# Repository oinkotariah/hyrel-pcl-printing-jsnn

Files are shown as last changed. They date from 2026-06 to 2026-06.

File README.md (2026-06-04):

# hyrel-pcl-printing-jsnn

PrusaSlicer configs, G-code, and patch scripts for **3D printing PCL (polycaprolactone) on the Hyrel SYSTEM 30M** by Direct Ink Writing (DIW), at the IMPACT Lab, JSNN (the Joint School of Nanoscience and Nanoengineering — NC A&T + UNCG).

The point of this repo is to **make the lab's settings reproducible** — so when we publish, the methods section can point here and anyone can re-slice the same STL with the same configs and get the same G-code.

---

## Project status — June 4, 2026 (Day 3 pivot)

**The live project is now a flexible conductive PCL/graphite composite, not bone-tissue scaffolds.** Same printer, same PCL, but the application has shifted to **flexible electronics**:

- **Goal:** PCL loaded with graphite at 5 loadings (10–30 %), formed into dog-bone specimens, measure conductivity to locate the **percolation threshold**. Poster now, paper later.
- **Hardware:** Hyrel SYSTEM 30M currently **down** (heads/nozzles reordered). Fallback fabrication route = melt-and-mould-cast.
- **Papers in scope** (5): Yuk 2020 (north star · printing a conductor), Zhang 2021 (PCL DIW how-to), Teixeira 2026 (parameter optimization), Liu 2018 (PCL melt-extrusion crystallinity), Woodruff & Hutmacher 2010 (PCL review). All summarized in `docs/research_notes/`.

The travel-speed G-code fix story below remains accurate as historical / methodological context. The `gcode/` and `configs/` folders are still the canonical settings if the Hyrel comes back online.

**For full current context** (paste into a fresh chat to restore state): see `docs/PROJECT_HANDOFF.md`.

---

## Quick start

If you just want to print our calibration cube:

1. Open PrusaSlicer 2.9.2 or newer.
2. Load these three profiles (under Print Settings, Filament Settings, Printer Settings):
   - **Print:** `configs/prusaslicer/print/PCL_DIW_25print_60travel_FIXED.ini`
   - **Filament:** `configs/prusaslicer/filament/ABS-30M_240C_80Cbed.ini` *(placeholder — will be replaced with a PCL-specific profile, see [Known issues](#known-issues))*
   - **Printer:** `configs/prusaslicer/printer/30M-ESR_T1_Heated.ini`
3. Import `gcode/cube_10x10x10_2mm_Corners/source.stl`.
4. Slice. The output should be ~7,000 lines and use **two F-values**: F1500 (25 mm/s, print) and F3600 (60 mm/s, travel).
5. Load the resulting G-code into Repetrel.
6. Print.

If PrusaSlicer isn't available, the pre-sliced fixed G-code is at `gcode/cube_10x10x10_2mm_Corners/travel_fixed.gcode`.

---

## What was actually fixed (the F1500 → F3600 story)

On 2026-06-01, the lab's calibration print of `cube_10x10x10_2mm_Corners` showed obvious stringing during travel moves between separated paths. We diagnosed the G-code and found:

| Measurement | Value |
|---|---|
| Travel-only moves (G1 X Y, no E) | 242 |
| Print moves (G1 X Y with E) | 5,732 |
| Unique F values in the entire 7,013-line file | **F1500 only** |

That meant every travel move was crawling at 25 mm/s (same as print speed), so the ink had time to ooze during each repositioning.

**Root cause:** In `PCL_DIW_25print_25travel_BROKEN.ini`, *every* speed setting was 25 mm/s — including `travel_speed`. PrusaSlicer only emits a new `F` value when the speed *changes* between moves, so it emitted F1500 once at the top of the file and never wrote another F.

**Fix:** Change one line — `travel_speed = 25` → `travel_speed = 60` — in the print-settings INI. Now PrusaSlicer differentiates between print and travel and writes F3600 on every travel move. The fixed profile is at `configs/prusaslicer/print/PCL_DIW_25print_60travel_FIXED.ini`.

**Why 60 mm/s:** Zhang 2021 and the DIW literature recommend travel = 3–10× print speed. With our 25 mm/s print, 60 mm/s (2.4×) is the conservative middle of the 30–80 mm/s DIW range. Bump higher once 60 is proven stable.

We also produced a hand-patched G-code at `gcode/cube_10x10x10_2mm_Corners/travel_fixed.gcode` using `scripts/patch_travel_speed.py` — useful for printing the fix without re-slicing.

---

## Repo layout

```
hyrel-pcl-printing-jsnn/
├── README.md                  ← this file
├── CONTRIBUTING.md            ← how to add a new ink, new geometry, new print run
├── LICENSE                    ← MIT
├── .gitignore
│
├── configs/
│   └── prusaslicer/
│       ├── printer/           ← Hyrel printer profile(s)
│       ├── filament/          ← material/temperature profile(s)
│       ├── print/             ← speed / extrusion / retraction profile(s)
│       └── recipes_naming_conventions.txt
│
├── gcode/
│   └── <part_name>/
│       ├── source.stl         ← CAD source
│       ├── original_*.gcode   ← sliced output, untouched
│       ├── *_fixed.gcode      ← any patched variants
│       └── notes.md           ← per-part observations
│
├── scripts/
│   ├── patch_travel_speed.py  ← adds F values for travel/print moves
│   ├── analyze_gcode.py       ← diagnostic: counts moves, lists unique Fs
│   └── README.md
│
├── docs/
│   ├── keywords.md            ← keyword/glossary cheat sheet
│   ├── papers.md              ← references (citations only, no PDFs)
│   └── glossary.md            ← short technical glossary
│
└── runs/
    └── YYYY-MM-DD_<short_description>/
        ├── notes.md           ← what we changed, what we observed
        ├── photos/            ← print result photos (gitignored if large)
        └── settings/          ← INI snapshot used for this run
```

### Naming conventions for files

**Print profiles:** `<material>_<process>_<print_speed>print_<travel_speed>travel_<status>.ini`
Examples:
- `PCL_DIW_25print_25travel_BROKEN.ini`
- `PCL_DIW_25print_60travel_FIXED.ini`
- `PCLPEO_DIW_5print_30travel_v1.ini`

**G-code variants:** Stored inside a `gcode/<part_name>/` folder. Always keep the **original** slicer output untouched as `original_<descriptor>.gcode`. Patched variants get a suffix like `_travel_fixed`, `_retract_added`, etc.

**Run folders:** `runs/YYYY-MM-DD_<lowercase_underscore_description>/`. One folder per session. Each has its own `notes.md`.

---

## Workflow

### To run a new test print

1. Decide what you want to test (new ink? new speed? new geometry?).
2. Make a new folder under `runs/` with today's date.
3. Choose existing config profiles in `configs/prusaslicer/` — or copy one to a new file with a clear name if you're changing settings.
4. Snapshot the exact INI(s) you used into `runs/<your_run>/settings/`.
5. Slice → load into Repetrel → print.
6. Photograph the result. Drop photos in `runs/<your_run>/photos/`.
7. Write up what you changed and what happened in `runs/<your_run>/notes.md` (template in `CONTRIBUTING.md`).
8. If you patched the G-code, commit both the original and the patched file under `gcode/<part_name>/`.
9. Commit. Push.

### To diagnose a G-code problem

```bash
python3 scripts/analyze_gcode.py path/to/file.gcode
```

It prints the count of travel vs. print moves, lists every unique `F` value, and flags suspicious patterns (like a file with only one F-value).

### To patch an existing G-code's travel speed

```bash
python3 scripts/patch_travel_speed.py input.gcode output.gcode --travel-f 3600 --print-f 1500
```

`--travel-f` and `--print-f` are in mm/min. Defaults are 3600 (60 mm/s) and 1500 (25 mm/s).

---

## Known issues / TODOs

- **Filament profile mismatch.** The current `ABS-30M_240C_80Cbed.ini` is set up for melt extrusion of ABS at 240 °C with an 80 °C bed. We're doing room-temperature DIW of PCL — the profile needs to be replaced with a PCL-DIW-appropriate one (likely with `temperature = 25` or similar, depending on Nick's heated vs. unheated head choice).
- **Retraction is 0.** `retract_length = 0,0,0,0,0` in the printer profile. For solvent-based DIW with stringing problems, 1–3 mm of retraction would likely help. Talk to Nick before changing.
- **No PCL/PEO ink profile yet.** Once we know the exact ink formulation (solvent system, concentration, ± PEO), we should add a print profile with that information in the filename.
- **No `runs/` history yet.** The first one is the 2026-06-01 diagnosis (under `runs/2026-06-01_day1_travel_speed_diagnosis/`).

---

## References

The methodology in this repo draws on three papers, all summarized in `docs/papers.md`:

1. **Zhang et al. 2021** — *Direct ink writing of polycaprolactone / polyethylene oxide based 3D constructs.* Progress in Natural Science: Materials International, 31, 180–191. (The closest published match to our workflow.)
2. **Teixeira et al. 2026** — *A simple method to assess the optimum 3D printing parameters, using agarose hydrogel.* MRS Communications, 16, 212–218. (Parameter sweep methodology.)
3. **Yuk et al. 2020** — *3D printing of conducting polymers.* Nature Communications, 11:1604. (The long-game endpoint.)

PDFs are NOT committed to this repo (copyright). Lab members can access them via the institutional library or the lab's shared drive.

---

## Authors / contributors

- **Onengiyeofori "Nengi" Inko-Tariah** — REU student, AAMU EE — initial diagnosis and patch (June 2026).
- **Nick Ricks** — graduate mentor, IMPACT Lab.

---

## License

MIT. See `LICENSE`. The configs are derivatives of PrusaSlicer's output (

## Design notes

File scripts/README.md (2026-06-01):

# scripts/

Small Python utilities for G-code work on the Hyrel.

## `analyze_gcode.py`

Diagnostic. Tells you what's actually in a G-code file: travel-vs-print move counts, every unique `F` value, and warnings for common problems (like the "only one F value in the whole file" sticky-F bug).

```bash
python3 scripts/analyze_gcode.py gcode/cube_10x10x10_2mm_Corners/original_BROKEN.gcode
```

Output for our broken cube:
```
=== ...original_BROKEN.gcode ===
Total lines:         7013
Travel moves:         242
Print moves:         5732

Unique F values (any move):
  F1500.0   →  25.00 mm/s   (appears 40×)

⚠️  Only ONE F value (F1500.0 = 25 mm/s) appears in the whole file.
   Travel and print are running at the same speed — likely the 'sticky F' bug.
```

## `patch_travel_speed.py`

Hand-patches a G-code to set explicit feedrates on travel and re-entry print moves. The fix-of-last-resort when re-slicing isn't possible.

```bash
# Default: travel = F3600 (60 mm/s), print = F1500 (25 mm/s)
python3 scripts/patch_travel_speed.py input.gcode output.gcode

# Custom travel speed (e.g., 80 mm/s = F4800)
python3 scripts/patch_travel_speed.py input.gcode output.gcode --travel-f 4800
```

The script adds a header comment block to the output file explaining what changed.

**The right way to fix the sticky-F problem is still to re-slice with `travel_speed > print_speed` in the print profile.** This script exists for the cases where you can't.

## Requirements

Python 3.8+. No external libraries.

## Adding new scripts

If you write a script and it's likely to be reused:

1. Put it here as `scripts/<verb>_<noun>.py` (e.g. `scripts/strip_layer_change_commands.py`).
2. Module docstring at the top explaining what it does and a USAGE block.
3. Use `argparse` for CLI args, no positional magic.
4. Update this README with a one-paragraph blurb and an example invocation.

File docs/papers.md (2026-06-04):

# Reference papers

**PDFs are not committed (copyright).** Citations + links only here. Access PDFs via
the AAMU library or the lab shared drive. Open-access ones are linked directly below.

---

## Zhang et al. 2021 — *the most directly relevant (method)*

**Citation:** Zhang, B., Chung, S. H., Barker, S., Craig, D., Narayan, R. J., & Huang, J. (2021). Direct ink writing of polycaprolactone / polyethylene oxide based 3D constructs. *Progress in Natural Science: Materials International*, **31**(2), 180–191. https://doi.org/10.1016/j.pnsc.2020.10.001
**Access:** OPEN ACCESS (CC BY-NC-ND). Free PDF: https://bura.brunel.ac.uk/handle/2438/27125

**Why it matters here:** The closest published method to what this lab does. PCL (hydrophobic) is DIW-printed by dissolving in DCM or acetone and using solvent evaporation as the "set" step.

**Key results to use:**
- DIW travel speed range: 30–80 mm/s (vs. print 2.5–12.5 mm/s).
- DCM beats acetone for shape fidelity due to better viscosity recovery (93% vs ~30% at 100 s).
- The three rheology tests every ink should pass: shear viscosity sweep, oscillatory yield-stress sweep, creep recovery test.
- ≥ 80% viscosity recovery within ~90 s is the working rule.
- Power-law index n < 1 is required for extrusion.

---

## Teixeira et al. 2026 — *parameter-sweep method*

**Citation:** Teixeira et al. (2026). A simple method to assess the optimum 3D printing parameters, using agarose hydrogel. *MRS Communications*, **16**, 212–218.
**Access:** PAYWALLED (Springer). Get via AAMU library proxy. Do NOT commit the PDF.

**Why it matters here:** The methodology backbone for parameter sweeps — the workflow for finding the best print speed × pressure × nozzle once an ink is loaded.

**Key results to use:**
- Best line accuracy 97.3% at 2 %w/v agarose, 25G, 6 mm/s, 40 kPa.
- A 3 %w/v thickener (laponite) lifted grid accuracy 60% → 83%. PEO plays the same role for PCL inks.
- Accuracy: `Accuracy(%) = (1 − |A_exp − A_CAD| / A_CAD) × 100`
- Square-pore printability: `Pr = L² / (16·A)`. Pr = 1 is perfect.

---

## Yuk et al. 2020 — *the long-game vision*

**Citation:** Yuk, H., Lu, B., Lin, S., Qu, K., Xu, J., Luo, J., & Zhao, X. (2020). 3D printing of conducting polymers. *Nature Communications*, **11**, 1604. https://doi.org/10.1038/s41467-020-15316-7
**Access:** OPEN ACCESS. Free at nature.com; PMC7105462.

**Why it matters here:** The endpoint the lab heads toward — conductive polymer 3D printing (9-channel soft neural probe from PEDOT:PSS).

**Key results to use:**
- Printable PEDOT:PSS nanofibril window: 5–7 wt%.
- Dry conductivity 155 S/cm; hydrogel state 28 S/cm.
- < 5% conductivity drop over 10,000 bending cycles.
- Multi-material: conductive electrodes printed *inside* a PDMS encapsulation in one job.

---

## Bone composite — *your actual end goal (NEW)*

These are the references that match where the project is headed: a PCL + mineral
scaffold that mimics bone. The "ground bone / calcium carbonate" you're adding is the
same idea as **hydroxyapatite (HAp)** in the literature.

**Zhang et al. 2022.** Direct ink writing of vancomycin-loaded polycaprolactone / polyethylene oxide / hydroxyapatite 3D scaffolds. *Journal of the American Ceramic Society*. https://doi.org/10.1111/jace.18048
- HAp added at 55–85% w/w to mimic bone mineral; **65% w/w ≈ the inorganic content of natural bone** and gave the best viscosity recovery + mechanical properties. This is the direct precedent for your composite.

**Kolan et al. 2018.** Solvent and melt-based extrusion 3D printing of polycaprolactone bioactive glass composite for tissue engineering. *Pro-AM 2018*, 176–182. https://doi.org/10.25341/D4B018
- Both melt and solvent routes for a PCL + mineral (bioactive glass) composite scaffold. Cited by the Hampton PREM poster.

**Varntanian, S. 2017.** 3D Printing of Polycaprolactone Scaffolds. https://doi.org/10.13140/RG.2.2.27949.28645

**Prior work (context, not a journal ref):** Horton, G. & Dumas, J. *3D Printing Polycaprolactone with Bone Composite.* PREM poster, Hampton University (NSF-DMR 1827820). Heated melt extrusion of PCL (Mw 14k → 80k), 60–95 °C, 20G→26G needles. — *Reference the approach; do not host the PDF (not ours).*

---

## Suggested reading order

1. **Zhang 2021** — your core DIW workflow.
2. **Zhang 2022 + Kolan 2018** — the bone-composite precedent; this is your poster's "why."
3. **Teixeira 2026** — the optimization protocol once you have a stable ink/composite.
4. **Yuk 2020** — long-term vision.

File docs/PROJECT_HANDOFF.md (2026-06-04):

# PROJECT HANDOFF — JSNN / IMPACT Lab Co-op

*Paste this into a fresh chat to restore full context. The new (co-op) chat already has most of the paper PDFs, so this is **context + decisions + plan**, not a re-dump of the papers.*

**How to use:** paste this whole file + a one-liner about what you need right now (e.g., "standing at the bench, about to mix the first composite batch — walk me through it"). The 5 PDFs are already attached in the co-op chat.

---

## 0. Snapshot
- **Nengi (Onengiyeofori Inko-Tariah)** — EE sophomore (AAMU), on an **NSF REU at the IMPACT Lab, JSNN** (NC A&T + UNCG). Mentor: **Nick Ricks**.
- **Current project:** a **flexible conductive polymer composite** — polycaprolactone (PCL) loaded with **graphite** — formed into **dog-bone specimens** to find the **percolation threshold** (conductivity vs graphite loading). Poster now, paper later.

## 1. The pivot (read first)
- Started as **PCL for bone-tissue-engineering scaffolds**.
- **Pivoted to flexible electronics:** Nick isn't pursuing bone; the goal is flexible electronics using **PCL as a flexible substrate + a conductor** (graphite filler, possibly **polyaniline/PANI** later).
- So all bone/scaffold material in the notes is **background**; the live application is a flexible *conductive* composite.

## 2. Goal
- Make **PCL + graphite** composites and **measure the sample's intrinsic conductivity** (multimeter → resistance → conductivity) across graphite loadings → **percolation plot** (conductivity vs graphite %) for the poster.

## 3. Materials
- **PCL 8,000 MW** for the composite (low-MW → low viscosity, easy to mix; but **brittle + more crystalline**).
- Earlier work used **PCL 14,000** (also brittle/low-MW).
- A **"PCL 300"** was called "the flexible one" — **CONFIRM with Nick** (its MW + whether it's the matrix or a plasticizer; low MW alone = *more* brittle, so "flexible" only makes sense if it's a soft additive).
- **Graphite** = conductive filler. Possibly **PANI** as an intrinsic conductor later.

## 4. Equipment & fabrication routes
- **Hyrel SYSTEM 30M** (DIW/melt extrusion), run via **Repetrel**. **Printer is currently down** — heads/nozzles reordered, Nick emailing Hyrel.
- Two fabrication routes:
  - **A. Extrude/print** dog-bones via the heated head (pressured + sheared).
  - **B. Melt in a beaker (no pressure) → pour into dog-bone moulds** (fallback if printer stays down).
- Either route yields composites + conductivity data → **the poster works with or without the printer.**

## 5. Experiment plan
- **5 graphite loadings**, ~**10–30%** (likely 10/15/20/25/30% — confirm spacing & wt% vs vol%).
- Form dog-bones, measure conductivity, plot vs loading → percolation threshold.
- **Replicates (n≈3)** per condition for credibility.

## 6. Critical pitfalls / cautions (from a full read of the 5 papers)
1. **Contact resistance** — 2-point multimeter includes probe/lead resistance, worst on the **conductive (high-graphite)** samples. Yuk used a **4-point probe**; at minimum use fixed **silver-paste contacts**, not hand-pressed tips.
2. **Geometry** — dog-bone cross-section isn't uniform; probe the **straight gauge** and **measure the actual cross-section** (don't assume nozzle/CAD size). σ = L/(R·A).
3. **Range** — insulating (low-graphite) samples may read **"OL"** on a handheld meter — expected (below percolation), not a failure. Use an instrument spanning the range.
4. **Graphite settling** — in low-viscosity 8k melt (esp. no-pressure cast), graphite sinks → conductivity gradient. Stir right before pouring; thin parts / short melt time.
5. **Aging** — PCL keeps crystallizing for hours-days → conductivity & brittleness drift. **Measure every sample at the same age.**
6. **8k brittleness** — samples crack on handling/clamping → broken network → erratic readings.
7. **Nozzle size is a confound, not a neutral knob** — smaller nozzle → more shear → aligns particles → higher/anisotropic conductivity (Yuk). Varying nozzle measures a *process* effect, not intrinsic material conductivity.
8. **Unprintable corner** — small nozzle + high graphite % → clogs.
9. **Combinatorial blowup** — full nozzle×graphite×replicate grid = dozens of samples (the "days"). **Screen the printable window first** (Teixeira), don't brute-force.

## 7. The key strategic decision (raise with Nick)
- Goal = **intrinsic** conductivity → **fix one nozzle (or cast), sweep graphite % only.** ~15 samples, clean curve.
- If instead studying **how print settings change the printed part** → nozzle×graphite is the right (bigger) *process* study, but it describes the printed part, not the material.
- Nozzle size is the crux; the two goals are in tension.

## 8. The 5 papers & roles (PDFs already in the co-op chat)
- **Yuk et al. 2020** (Nat. Commun. 11, 1604) — ***north star***: 3D printing a conductor (PEDOT:PSS); <5% conductivity drop over 10,000 bends; percolation via dry-annealing; 4-point conductivity.
- **Zhang et al. 2021** (Prog. Nat. Sci. Mater. Int. 31, 180–191) — PCL DIW how-to; ink rules (shear-thinning + >80% recovery); **DCM beats acetone**.
- **Teixeira et al. 2026** (MRS Commun. 16, 212–218) — parameter-optimization method (sweep, measure accuracy by area, find printable window). Directly applicable.
- **Liu et al. 2018** (Macromol. Mater. Eng. 303, 1700494) — melt extrusion changes PCL crystallinity/orientation; why printed PCL came out brittle. (Crystallography deep-dive parked for the "Drakes" polymer class.)
- **Woodruff & Hutmacher 2010** (Prog. Polym. Sci. 35, 1217–1256) — broad PCL review; now background.

## 9. Open questions for Nick
1. Graphite ratios + **wt% vs vol%**.
2. Conductor: graphite only, or graphite + PANI?
3. What **"PCL 300"** is (MW + role).
4. Fallback (mould) route step order; what the **blender** step is for.
5. **Mechanical** (tensile) testing in scope, or electrical only?
6. Intrinsic-conductivity **vs** process-study question (§7) — decides whether to sweep nozzle.
7. Repo notes — keep bone framing as background?

## 10. File manifest (everything produced)
**Canonical notes — use these (`research_notes/`):**
- `00_README.md` — index / reading order
- `01_PCL_fundamentals_review.md` — PCL fundamentals (cited)
- `02_conducting_polymers_PANI_primer.md` — conducting polymers & PANI (cited)
- `03_printing_and_preparation.md` — fabrication methods (cited)
- `04_conductive_composite_gameplan.md` — the experiment plan (cited)
- `05_liu_section3_crystallography_decoder.md` — plain-English XRD/crystallography decoder

**Other current files (top level):**
- `abstracts_and_materials.md` — all 5 papers' abstracts + materials, with PDF page locations
- `source_referenced_facts.md` — poster-ready facts, each with page/figure citation
- `papers.md` — reference list (has bone-composite refs; some framing now background)
- `print_run_log.md` — one-row-per-attempt experiment log template (still useful for the composite runs)

**Pre-pivot / historical (from the Day-1 travel-speed fix; keep for the record):**
- `mock_paper_PCL_DIW_travel_fix.md` — early mock paper
- `travel_fixed_ANNOTATED_READING_COPY.gcode` — annotated G-code

**Superseded (replaced by the `research_notes/` versions — kept for completeness):**
- `PCL_review_summary_notes.md` → use `research_notes/01`
- `conducting_polymers_PANI_primer.md` → use `research_notes/02`
- `printing_and_preparation_summaries.md` → use `research_notes/03`
- `conductive_composite_gameplan.md` → use `research_notes/04`

## 11. How I've been helping (so the new chat matches the style)
- Paper claims get **inline citations with page/figure** (e.g., "(Yuk 2020, p.4, Fig.3)"); general/textbook facts are **left uncited rather than faking a source**.
- **Honest flags** when something could undermine the experiment or doesn't match the stated goal — with mitigations.
- Step-by-step, structured deliverables; explanations tied to actual files/photos.

## Other threads (non-research, low priority)
- **Entrepreneurship / CEE&I at NC A&T:** met director **Shawn Johnson** (brief pitch coaching). Action item — email **Dr. Curry** to get on CEE&I updates (a warm draft was already written).

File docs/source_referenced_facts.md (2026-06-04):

# Source-Referenced Key Facts

*Each claim paired with its exact location so you can cite it on the poster. Format: claim — (Author Year, page / Figure / Section). Page numbers are the journal page printed on the PDF. ⭐ = most likely to go on the poster.*

*Note: none of these five is the PCL+graphite composite paper, so anything about the **percolation threshold / graphite loading** must be cited to that paper (not yet in this set) — don't pin it to these.*

---

## Yuk et al. 2020 — conducting polymers (Nat. Commun. 11, 1604) — *your north star*
- ⭐ Conductivity **155 S/cm (dry), 28 S/cm (hydrogel)** — (Yuk 2020, p.4, Fig.3a).
- ⭐ **<5% conductivity change** across bending radii; still **>100 S/cm (dry) / >15 S/cm (hydrogel) after 10,000 bends** — (Yuk 2020, p.4, Fig.3b–c).
- ⭐ Printable ink window **5–7 wt%** PEDOT:PSS nanofibrils (below → spreads, above → clogs) — (Yuk 2020, p.2, Fig.1m,o).
- Young's modulus **1.5 GPa dry vs 1.1 MPa hydrogel** (soft as PDMS) — (Yuk 2020, p.5, Fig.3f).
- Resolution to a **30 µm nozzle**, up to **20 layers** high aspect ratio — (Yuk 2020, p.3, Fig.2).
- Multi-material with insulating PDMS; **9-channel neural probe, 30 µm electrodes, 50–150 kΩ @1 kHz** — (Yuk 2020, p.5, Fig.4d).
- Ink prep: cryo-freeze → lyophilize → redisperse in **water:DMSO 85:15**; then **dry 60 °C, anneal 130 °C** — (Yuk 2020, Methods, p.6–7).

## Zhang et al. 2021 — DIW of PCL/PEO (Prog. Nat. Sci. Mater. Int. 31, 180–191) — *your PCL-DIW how-to*
- ⭐ The **three DIW ink rules**: shear-thinning, clean filament, **>80% viscosity recovery** after deposition — (Zhang 2021, p.2, Intro).
- ⭐ **DCM ink recovered ~93%** (full by ~100 s); **acetone inks <80%** (44% low / 81% high conc.) → **DCM preferred** — (Zhang 2021, p.6, Sect.3.1.2).
- All inks **power-law index n < 1** (shear-thinning) — (Zhang 2021, p.5, Fig.3c–d).
- Acetone ink shear rate **~9× higher** than DCM at same flow (1702.9 vs 195.2 s⁻¹) — (Zhang 2021, p.7, Sect.3.2).
- Materials: **PCL Mn ~80,000, PEO Mn ~200,000**; PCL:PEO **1:1**; **24G nozzle** — (Zhang 2021, p.2, Sect.2.1–2.2).
- Print window: speed **2.5–12.5 mm/s**, flow **0.48–1.44 mm³/s**; best fidelity DCM @ **5 mm/s + 0.48 mm³/s** — (Zhang 2021, p.3 & p.8, Sect.2.3.3 / 3.3).
- PCL/PEO **immiscible**; raw Tm PCL **60.9 °C**, PEO **70.2 °C** — (Zhang 2021, p.8, Fig.7b).
- PEO addition raised wettability (contact angle D_PCL **74.3°** → D_PCL/PEO **37°**) — (Zhang 2021, p.10, Fig.8d).

## Teixeira et al. 2026 — parameter optimization (MRS Commun. 16, 212–218) — *your optimization playbook*
- ⭐ Best line accuracy **97.3%** at **2% agarose, 25G, 6 mm/s, 40 kPa** — (Teixeira 2026, Abstract p.1 & Results p.5).
- ⭐ **Accuracy = (1 − |A_exp − A_CAD| / A_CAD) × 100** (Eq.1) — (Teixeira 2026, p.3).
- ⭐ **Pore printability Pr = L² / 16A**; Pr = 1 perfect, <1 under-gelation, >1 over-gelation (Eq.3) — (Teixeira 2026, p.4).
- Parameters swept: speed **1–10 mm/s**, pressure **40–100 kPa**, gauge **25G/27G/30G** — (Teixeira 2026, p.3).
- **3% laponite** raised grid accuracy **60.3% → 83.5%** — (Teixeira 2026, p.5, Fig.4).
- Rule of thumb: to raise accuracy, **↑ speed & gauge, ↓ pressure** — (Teixeira 2026, p.6, Discussion).
- Method is **material-agnostic** for any shear-thinning ink — (Teixeira 2026, p.2 & Conclusions p.6).

## Liu et al. 2018 — melt-extrusion crystallinity (Macromol. Mater. Eng. 303, 1700494)
- Screw-assisted melt extrusion: **0.5 mm nozzle, 10 rpm, 110 °C → 0.1 mm/s** — (Liu 2018, p.2, Sect.2.1).
- PCL **CAPA6500, Mw 50,000**; Tm **58–60 °C**, Tg **−60 °C** — (Liu 2018, p.2, Sect.2.2).
- Spherulite size **~40 µm (pellet) → <4 µm (printed)** — (Liu 2018, p.2, Fig.2).
- Crystals **align in flow direction**; crystal volume fraction **increases down the nozzle**; driven by undercooling + shear — (Liu 2018, p.4–5, Figs.4–5).

## Woodruff & Hutmacher 2010 — PCL review (Prog. Polym. Sci. 35, 1217–1256)
- ⭐ PCL **Tg −60 °C, Tm 59–64 °C**; MW **3,000–80,000**; **crystallinity decreases as MW rises** — (Woodruff 2010, p.3, Sect.2).
- ⭐ Soluble in **chloroform/DCM**; **poor in acetone**; insoluble in alcohols — (Woodruff 2010, p.3, Sect.2).
- Degradation **2–4 years**; two-stage (hydrolysis, then intracellular below MW ~3,000) — (Woodruff 2010, p.4–5, Sect.3).
- Fabrication-method table (porosity & pore size per method) — (Woodruff 2010, Fig.9).
- *(bone background)* mPCL + **20 wt% β-TCP**; commercialized as Osteopore — (Woodruff 2010, Sect.8.2 & 10, p.24–25, 35).

---

## How to use this on the poster
- When you state a number, copy the parenthetical — e.g., "*…holds conductivity through 10,000 bends (Yuk 2020).*"
- In a reference list, the **index numbers** are inside each paper's own bibliography; the **journal + year + page** here is enough to find any claim fast.
- If a reviewer asks "where's that from?", you can point to the exact page/figure in seconds.

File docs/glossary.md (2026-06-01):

# Glossary

Short definitions only. The full keyword/reference doc lives at `docs/keywords.md`. This one is the "I need to recall a single term" lookup.

## G-code

| Term | Meaning |
|---|---|
| F | Feedrate — toolhead motion speed in mm/min. Sticky. |
| E | Extruder amount — mm of filament, OR mm³ if M229 volumetric mode is enabled. |
| G0 | Rapid (travel) move. No extrusion. |
| G1 | Controlled move. Print if E is present; travel if not. |
| G28 | Home all axes. |
| G92 | Set current position. Used for Z-offset. |
| M104 / M109 | Set extruder temp, no wait / with wait. |
| M140 / M190 | Set bed temp, no wait / with wait. |
| M229 E1 D1 | Enable volumetric E (Hyrel always uses this). |
| M756 S[h] | Hyrel: set layer height. |
| M727 / M729 | Hyrel: prime / un-prime head. |
| T0 / T1 / T12 | Tool slot select on Hyrel. |

## Slicer settings

| Term | Meaning |
|---|---|
| travel_speed | Feedrate when not extruding. Should be 3–10× print speed for DIW. |
| perimeter_speed | Print speed for outer walls. |
| extrusion_multiplier | Scales E values. 0.95–1.05 normal range. |
| retract_length | mm of filament pulled back before travel. |
| retract_lift / Z-hop | Lift nozzle during travel to clear print. |
| wipe | Sideways nozzle wipe during retraction. |

## Materials

| Term | Meaning |
|---|---|
| PCL | Polycaprolactone. Biodegradable polyester, melts ~60 °C. |
| PEO | Polyethylene oxide. Water-soluble. Blended 1:1 with PCL for wettability. |
| PEDOT:PSS | Most-used conducting polymer. Watery dispersion as sold. |
| PANI | Polyaniline. Conducting polymer. Lab's eventual target. |
| PDMS | Silicone elastomer. Soft, biocompatible, insulating. |
| DCM | Dichloromethane. PCL solvent. Toxic, fume hood required. |
| ACE | Acetone. Alternative PCL solvent. Inferior viscosity recovery vs DCM. |

## Rheology

| Term | Meaning |
|---|---|
| Shear-thinning | Viscosity drops as shear rate rises. Required for DIW. |
| Yield stress | Minimum stress to initiate flow. |
| Power-law index (n) | < 1 = shear-thinning. n = 1 = Newtonian. |
| Recovery (%) | Viscosity returned after shear stops. ≥ 80% in 90 s. |
| Thixotropy | Shear-thinning + recovery combined. |
| Filament fidelity | Printed line width ÷ nozzle diameter. ~1.0 ideal. |
| Pore printability (Pr) | L²/(16·A). Pr = 1 = perfect square pore. |

## Hyrel hardware

| Term | Meaning |
|---|---|
| SDS-10 | Smooth Driven Syringe, 10 cc reservoir. The DIW workhorse. |
| EMO | Emulator Motor Output. Heated melt extruder. |
| VOL | Volumetric head. High-precision flow control. |
| Repetrel | Hyrel's proprietary printer-control program. NOT a slicer. |
| ESR | Engineering Solutions Researcher. A Hyrel SYSTEM 30M variant. |
| T1 / T12 | Tool slot positions on the Hyrel. |

## Software

| Term | Meaning |
|---|---|
| Slic3r | Original open-source slicer (MIT). |
| PrusaSlicer | Slic3r fork. The slicer this lab uses. |
| Repetrel | Hyrel's printer controller (not a slicer). |
| STL | 3D mesh file format (slicer input). |
| G-code | Plain-text printer instructions (slicer output). |
| ImageJ | Free image analysis (used in Teixeira for line measurements). |

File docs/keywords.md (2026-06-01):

# Lab Keywords — Hyrel / PCL / DIW Reference

**For:** Next session at IMPACT Lab (Day 2+)
**Format:** Hand-copyable. Each entry is short. The trickier ones include "common wrong instinct" so you don't have to relearn it later.

---

## 🔑 START-HERE — the ones I was unsure about

### F (feedrate)
- **What it is:** How fast the toolhead (nozzle) moves. Units = mm/min.
- **Common wrong instinct:** "F = filament speed." NO. F is *motion* speed, not material speed.
- **Conversion:** Divide F by 60 to get mm/s. (F1500 = 25 mm/s. F3600 = 60 mm/s.)
- **Sticky:** Once written, F stays in effect for every following move until a new F is written. This is why the cube G-code was at 25 mm/s the whole file.

### E (extruder amount)
- **What it is:** How much material gets pushed out during a move.
- **Units:** Normally mm of filament. BUT — with `M229 E1 D1` (volumetric mode, which the Hyrel header turns on) E becomes **mm³** of ink. Big difference.
- **Mental model:** E = how much, F = how fast. Two different buckets.

### Slic3r vs. PrusaSlicer
- **Slic3r:** Original open-source slicer (MIT licensed). GitHub: slic3r/Slic3r.
- **PrusaSlicer:** A fork of Slic3r maintained by Prusa Research. **This is what Nick uses** (confirmed from G-code header: "generated by PrusaSlicer 2.9.2").
- Most settings have the same names in both. The Slic3r manual still works as a backup reference.
- **Repetrel:** Different thing. Hyrel's own program that runs the printer. Its built-in slicer integration is broken; that's why Nick uses standalone PrusaSlicer.

---

## 🧭 G-code commands — MOVEMENT

| Command | Plain-English |
|---|---|
| `G0` | Rapid (travel) move. No extrusion. |
| `G1` | Controlled move. May or may not extrude (depends on whether E is included). |
| `G28` | Home. Sends axes to the zero position. |
| `G92` | Set current position. Used to define Z-offset (e.g. `G92 Z0.1` says "treat this height as new zero"). |
| `G21` | Set units to millimeters. |
| `G90` | Absolute coordinates (X10 means "go to X=10"). |
| `G91` | Relative coordinates (X10 means "go 10 mm further in X"). |
| `G53` | Clear/cancel coordinate offsets. |

## 🌡️ G-code commands — TEMPERATURE & STARTUP

| Command | Plain-English |
|---|---|
| `M104 S[temp]` | Set extruder temp. **No wait** — continues to next command. |
| `M109 S[temp]` | Set extruder temp **and wait** until reached. |
| `M140 S[temp]` | Set bed temp, no wait. |
| `M190 S[temp]` | Set bed temp and wait. |
| `M82` | Absolute extrusion (E values are absolute totals). |
| `M83` | Relative extrusion (E values are deltas per move). |
| `M84` | Disable stepper motors. Usually at end of print. |
| `M106 C[val]` | Fan ON. C255 = 0–255 scale. |
| `M107` | Fan OFF. |
| `M5` | Spindle off (laser/spindle gear). |

## ⚙️ G-code commands — HYREL-SPECIFIC

| Command | Plain-English |
|---|---|
| `M229 E1 D1` | Enable **volumetric E-values** (E in mm³, not mm). Always in Hyrel's start G-code. |
| `M756 S[val]` | Set layer height. Hyrel calls this every layer change. |
| `M727 P[head]` | Prime head (push ink to the tip before printing starts). |
| `M729 P[head]` | Un-prime / retract head. |
| `M204 S[val]` | Set acceleration. |
| `M790` | Execute any new-layer actions. |
| `M772 S1` | Reset metrics + arm automatic reporting (housekeeping). |
| `M627` | Setup abort action — if something fails, this defines what happens. |
| `M620 T100 E0` | CO₂ lasers off. |
| `T0 / T1 / T12` | Select tool/head in slot 0, 1, or 12. Hyrel has multiple slots. |
| `M722 / M721` | Tool-change priming sequences (run during a swap between heads). |

## 📐 G-code parameters — INSIDE A LINE

A full move line looks like:
```
G1 X10.5 Y20.3 Z0.4 E5.2 F1500 ; description
```

| Letter | Meaning |
|---|---|
| `X` | X-axis position (mm, absolute by default). |
| `Y` | Y-axis position. |
| `Z` | Z-axis position (height). |
| `E` | Extruder amount. mm of filament — or **mm³** if M229 volumetric mode is on. |
| `F` | Feedrate (motion speed) in mm/min. Sticky. |
| `;` | Comment. Everything after is ignored by the printer. |

**Trick to know:** If a `G1` line has X/Y but NO E, it's a **travel move** (nozzle moves, nothing extruded). If it has X/Y **and** E, it's a **print move**.

---

## 🛠️ Slicer (PrusaSlicer / Slic3r) — KEY SETTINGS

### Speed settings
| Setting | What it controls |
|---|---|
| `travel_speed` | Feedrate when NOT extruding. Want this **higher** than print speed (3–10×) to reduce ooze during reposition. |
| `perimeter_speed` | Speed printing outer walls. |
| `external_perimeter_speed` | Speed printing the outermost visible wall (often slower for finish quality). |
| `infill_speed` | Speed for the fill pattern inside. |
| `first_layer_speed` | Speed for layer 1 only. Usually slower for adhesion. |
| `small_perimeter_speed` | Speed on tight curves / small radii. |
| `bridge_speed` | Speed when spanning a gap. |
| `max_print_speed` | Hard cap on any print speed. |

### Material flow
| Setting | What it controls |
|---|---|
| `extrusion_multiplier` | Scales the E values up/down. **0.95–1.05 is the normal tuning range.** Drop if over-extruding (blobs); raise if under-extruding (gaps). |
| `extrusion_width` | The width of the line the slicer expects each pass to lay down. |
| `first_layer_height` | Height of layer 1. Often equals layer_height; sometimes slightly larger for adhesion. |
| `layer_height` | Height of every layer after layer 1. |

### Retraction (anti-stringing)
| Setting | What it controls |
|---|---|
| `retract_length` | mm of filament/ink pulled back before a travel move. **Currently 0 in our config — likely the next thing to tune.** |
| `retract_speed` | How fast to retract. Faster = sharper "stop" of flow. |
| `retract_before_travel` | Minimum travel distance before retraction kicks in (so it doesn't retract every tiny hop). |
| `retract_lift` (Z-hop) | mm to lift the nozzle during travel so it doesn't drag across the print. |
| `wipe` | Tells the nozzle to wipe sideways while retracting, smearing the bead instead of leaving a blob. |

### Geometry / pattern
| Setting | What it controls |
|---|---|
| `perimeters` | Number of outer walls per layer. |
| `fill_density` | Infill percent (0%–100%). |
| `fill_pattern` | Rectilinear, honeycomb, gyroid, etc. |
| `top_solid_layers` / `bottom_solid_layers` | How many fully solid layers cap the part top and bottom. |
| `avoid_crossing_perimeters` | If true, travel paths route around walls instead of over them. Reduces stringing. |
| `only_retract_when_crossing_perimeters` | Retract only when a travel actually crosses a wall (not on every hop). |
| `skirts` / `brim_width` | Extra perimeter rings around the part (skirt = standalone; brim = touching the part) for first-layer priming/adhesion. |

---

## 🖨️ Hyrel SYSTEM 30M — HARDWARE

| Term | Meaning |
|---|---|
| **SDS-10** | Smooth Driven Syringe, 10 cc capacity. For paste/gel/melt at moderate viscosity. The DIW workhorse. |
| **EMO** | Emulator Motor Output. For melt extrusion (pellet-fed heated head). |
| **VOL** | Volumetric head. High-precision flow control. |
| **Hot End MK1 / MK2** | Standard FDM-style filament heads. Not our main use. |
| **Reservoir head** | Generic term for SDS/EMO/VOL — anything that holds ink in a reservoir vs. feeding from a spool. |
| **T0 / T1 / T12** | Tool slot positions on the Hyrel. T1 is the second slot from the left; T12 is a paired/heated slot. The printer config we're using is `30M-ESR_T1_Heated.ini`. |
| **ESR** | "Engineering Solutions Researcher" — a specific Hyrel SYSTEM 30M variant. |
| **Repetrel** | Hyrel's proprietary control program. Runs on the lab ThinkPad. Sends G-code to the machine + lets you do mid-print tweaks. |

---

## 🧪 MATERIALS

| Term | Plain-English |
|---|---|
| **PCL (polycaprolactone)** | Biodegradable hydrophobic polyester. Melt temp ~60 °C. FDA-approved. Tissue scaffolds, drug delivery, soft robotics. Your primary material. |
| **PEO (polyethylene oxide)** | Water-soluble hydrophilic polymer. Blends with PCL (1:1) to add wettability and surface roughness. |
| **PEDOT:PSS** | Most common conducting polymer. Sold as a watery dispersion (Clevios PH1000). Yuk 2020 turned it into a printable paste. |
| **PANI (polyaniline)** | Another conducting polymer. Chemically simpler than PEDOT:PSS. Eventual target for our blend work. |
| **PDMS (polydimethylsiloxane)** | Silicone elastomer. Soft, biocompatible, insulating. Used as the "body" of soft electronics. |
| **DCM (dichloromethane)** | Volatile organic solvent. Dissolves PCL well. **Toxic — needs a fume hood.** |
| **ACE (acetone)** | Less toxic solvent. Also dissolves PCL, but inks based on it recover viscosity worse than DCM ones (per Zhang 2021). |
| **Laponite** | Nanosilicate thickener. Used in Teixeira 2026 to rescue grid printability of weak agarose inks. PCL-world analog = PEO. |

---

## 🌊 RHEOLOGY & PRINTABILITY

| Term | Plain-English |
|---|---|
| **Shear-thinning** | Ink gets runnier as you push it harder. **Required for extrusion printing.** |
| **Yield stress** | The minimum stress needed to make the ink start flowing. Below it, the ink acts like a soft solid. Too low → drips. Too high → clogs. |
| **Power-law index (n)** | Number between 0 and 1. Lower = more shear-thinning. n = 1 means Newtonian (water-like). n > 1 means shear-thickening (NOT good for printing). |
| **Consistency index (m)** | Companion to n. Measures the magnitude of viscosity at low shear. |
| **Recovery (%)** | After you remove shear stress, how much of the original viscosity comes back. **≥ 80 % in ~90 s** is the working rule (Zhang). |
| **Thixotropy** | Combined idea: shear-thins on demand AND recovers when you stop. The full description of a "good DIW ink." |
| **Storage modulus (G′)** | Elastic component of the ink's response. High G′ = behaves more solid. |
| **Loss modulus (G″)** | Viscous component. High G″ = behaves more liquid. The crossover where G′ = G″ marks the yield point. |
| **Filament fidelity** | Printed line width ÷ nozzle diameter. ~1.0 is clean. >1 = ink is spreading. <1 = under-flow. |
| **Pore printability (Pr)** | For square-pore grids: Pr = L² / (16A). Pr = 1 = perfect; <1 = under-gelation; >1 = over-gelation. |
| **Woodpile construct** | Alternating perpendicular layer pattern. Standard DIW test geometry. |

---

## 📷 CHARACTERIZATION TOOLS

| Term | What it tells you |
|---|---|
| **ImageJ** | Free image-analysis software. Used in Teixeira 2026 for measuring line area / pore area from photographs. |
| **SEM** | Scanning Electron Microscope. Surface morphology at micron scale. |
| **SAXS** | Small-Angle X-ray Scattering. Nanofibril spacing / packing inside the polymer. |
| **XRD** | X-ray diffraction. Crystallinity and phase identity. |
| **DSC** | Differential Scanning Calorimetry. Melting temperatures, glass transition. |
| **TGA** | Thermogravimetric Analysis. How a material loses mass when heated (decomposition temps). |
| **FTIR** | Fourier Transform Infrared spectroscopy. Identifies chemical bonds in the sample. |
| **Contact angle (water)** | Drop a water droplet on the surface, measure the angle. Low angle = hydrophilic. High = hydrophobic. |
| **AFM nanoindentation** | Atomic Force Microscope used as a tiny mechanical tester. Measures Young's modulus at nm scale. |
| **EIS** | Electrochemical Impedance Spectroscopy. Used on conductive samples. Fits an equivalent circuit (R, C). |
| **CV** | Cyclic Voltammetry. Measures charge storage, redox stability of an electrode. |

---

## 💻 SOFTWARE / FILES

| Term | Plain-English |
|---|---|
| **STL** | Stereolithography file. A 3D mesh format. Slicer input. |
| **G-code** | Plain-text instructions for the printer. Slicer output. Lines like `G1 X10 Y20 E0.5 F1500`. |
| **`.ini`** | Slicer config file. Holds all the settings (speeds, retraction, etc.). PrusaSlicer reads these. |
| **Slic3r** | Open-source slicer. Original. MIT licensed. |
| **PrusaSlicer** | Slic3r fork. What Nick uses. Better-maintained, better docs. |
| **Repetrel** | Hyrel's proprietary control software. NOT a slicer — it runs the G-code on the machine. |
| **CAD** | Computer-Aided Design. SolidWorks, Fusion 360, etc. — where the STL comes from. |
| **Pronterface** | Open-source G-code sender / host. Zhang 2021 used this. Repetrel is the Hyrel equivalent. |

---

## ⚠️ MENTAL-MODEL TRAPS (common wrong instincts and the right one)

| You might think… | But actually… |
|---|---|
| F is filament speed. | F is **nozzle motion speed** in mm/min. E is the filament amount. |
| Every G-code line needs an F. | F is **sticky** — only written when speed changes. One F at the top can drive the whole file. |
| G0 vs G1 is travel vs print. | Loosely true, but PrusaSlicer often uses G1 for both. The actual difference is **whether E is present**: no E = travel, with E = print. |
| "Slic3r" means PrusaSlicer. | Slic3r is the parent project; PrusaSlicer is the fork Nick uses. The G-code header will say which one. |
| Repetrel is the slicer. | Repetrel is the **printer controller**. Slicing happens in PrusaSlicer first; Repetrel just runs the result. |
| Retraction = always good. | Retraction = pulling material back to stop ooze. Currently set to 0 in our config. Helpful for DIW with stringing, but too much causes blobs at restart. |
| PCL prints like ABS. | No. PCL melts at ~60 °C, ABS at ~240 °C. Currently the filament profile is set up for ABS — flag this. |
| Higher E = bigger line. | Higher E = more material pushed. Bigger line ALSO depends on speed (F). Same E at half the F gives a fatter line. |
| Two circles printing badly = retraction problem. | Could be retraction, **or** travel speed (which was our problem), **or** Z-hop, **or** "avoid crossing perimeters" setting. Diagnose by changing one thing at a time. |
| Adding more layers = same print, taller. | First-layer settings differ from subsequent layers. If layer 1 is wrong, every layer above it inherits the problem. |
| Volumetric (M229) means "vacuum." | Volumetric here means **E is measured in mm³ of material** instead of mm of filament length. The Hyrel always uses this. |

---

## 📚 PAPER SHORTHAND

| Paper | What it's the source of |
|---|---|
| **Zhang 2021** | PCL+PEO DIW. Solvent systems (DCM vs ACE). The 3-test rheology protocol. The 80% recovery rule. **My main paper.** |
| **Teixeira 2026** | Parameter-sweep methodology (concentration × pressure × speed × nozzle). Accuracy formula. Pore printability (Pr). |
| **Yuk 2020** | PEDOT:PSS soft neural probe. Cryo-lyophilization + redispersion method. The long-game vision paper. |

---

## 🎯 IF I FORGET EVERYTHING ELSE, REMEMBER THESE 5

1. **F = motion speed (mm/min). E = material amount. F is sticky.**
2. **DIW travel speed should be 3–10× print speed.** Print 2–15 mm/s → travel 30–80 mm/s.
3. **Nick uses PrusaSlicer, not Slic3r or Repetrel's slicer.** Repetrel is just the printer controller.
4. **Retraction is currently set to 0.** Adding 1–3 mm of retraction is probably the next stringing fix.
5. **The Hyrel uses volumetric E (mm³), not linear mm.** Don't compare E numbers to FDM-printer tutorials online — they assume linear mm.

---

*Print this out, fold it in the notebook, or pull it up on the phone at the bench. Update it when something new comes up — keep one running master file rather than starting a new one each week.*

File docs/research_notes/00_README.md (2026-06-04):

# Research Notes — Index

Study and literature notes for the JSNN / IMPACT Lab project. Drop this whole folder into your repo under `docs/`. Read in the numbered order.

---

## Project context (read this first)
The project started by exploring **PCL for bone-tissue-engineering scaffolds**, then **pivoted to flexible electronics** — using **PCL as a flexible substrate** combined with a **conductor** (graphite filler, and/or polyaniline). The PCL *fundamentals* still apply; only the *application* changed (bone scaffold → flexible conductor). So where the older notes talk about bone/scaffolds, treat that as background — the live goal is a **flexible conductive composite**.

---

## Reading order

**01 — PCL Fundamentals (`01_PCL_fundamentals_review.md`)**
What PCL is and why it's used: synthesis, Tg (−60 °C), Tm (~60 °C), molecular weight ↔ crystallinity, solubility, degradation. *Note: the bone-composite framing here is now background; the key property for the new project is PCL's **flexibility**.*

**02 — Conducting Polymers & PANI Primer (`02_conducting_polymers_PANI_primer.md`)**
The science behind the pivot: how conjugation creates a delocalized "electron cloud," why doping is needed (the silicon analogy), and how polyaniline switches conductive with acid. *Read sections 3–4 if nothing else.*

**03 — Printing & Preparation (`03_printing_and_preparation.md`)**
How these materials get made/shaped: solvent casting vs. melt processing, the fabrication-method menu, and where extrusion/direct writing fits. Covers both reference papers' printing/prep portions.

**04 — Conductive Composite Gameplan (`04_conductive_composite_gameplan.md`)**
The actual experiment: PCL + graphite, 5 loadings (10–30%), the percolation threshold, dog-bone specimens, conductivity testing, and both routes (3D print vs. mould-cast if the printer's down). Ties everything above together.

---

## Status / parked
- **Liu crystallinity paper** (deep XRD/crystal-orientation dive) — parked until after the polymers session with **Drakes**.
- **Bone-scaffold direction** — superseded by flexible electronics. Kept only as background.

## Open questions for Nick (from the gameplan)
1. Exact graphite ratios + wt% vs vol%.
2. Conductor: graphite only, or graphite + PANI?
3. Fallback route step order (melt / mix / sonicate / cool / blend).
4. What the blender step is for.
5. Whether mechanical (tensile) testing is in scope.

## Suggested next note (not yet written)
- A short **PANI deep-dive** or **Yuk 2020 summary** once PANI actually enters the mix.
- The **Liu crystallinity** summary after the Drakes session.

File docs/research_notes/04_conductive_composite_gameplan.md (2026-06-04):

# Conductive PCL–Graphite Composite — Project Gameplan & Process Notes

*Living doc. **[confirm w/ Nick]** = fuzzy/unstated detail.*

> **Citation note:** this gameplan is mostly **Nick's plan + general concepts** (percolation, the composite logic), so most of it carries no paper citation. Paper citations appear only where a step mirrors a **published method** — Teixeira's parameter optimization and Zhang's DIW rheology rules.

---

## The goal (one sentence)
Make a **flexible conductive composite** by loading **graphite into PCL**, find the **percolation threshold**, print/cast **dog-bone** specimens, and **test conductivity** — enough for a **poster now**, **paper later**.

## The core concept: percolation threshold *(general concept — cite your graphite-composite paper, not yet in the set)*
- Too little graphite → isolated particles → insulator.
- At threshold → connected network spans the part → conductivity jumps orders of magnitude.
- More than needed → conducts well but stiff/brittle.
- Target: **minimum graphite that still conducts** (keep flexibility).

## The experiment: 5 compositions
- **Range:** **10 → 30%** graphite, **5 points** (likely 10/15/20/25/30%) **[confirm: spacing, wt% vs vol%]**.
- **Why 5 points:** map conductivity vs loading, locate the percolation jump.
- This one-variable-at-a-time sweep to find the parameter window mirrors the published optimization approach in **Teixeira 2026** (sweep parameters, measure an outcome, find the usable window — Teixeira 2026, Sect."Materials and methods" & Discussion, p.3, p.6).

## ROUTE A — Primary (printer working): melt-compound + 3D print
1. **Melt** PCL in the heated head (replaces solvent dissolution).
2. **Mix in graphite** (melt compounding); disperse well (sonication). Good dispersion = consistent conductivity.
3. **Extrude / 3D print** into the dog-bone; solidifies on cooling.
4. **Test conductivity.**
- *If using a DIW/solvent ink instead, the ink must obey the rheology rules: shear-thinning + >80% viscosity recovery (Zhang 2021, Intro, p.2), and DCM outperforms acetone (Zhang 2021, Sect.3.1.2, p.6).*

## ROUTE B — Fallback (printer down): melt in beaker + mould-cast
1. **Melt PCL in a beaker.**
2. **Mix in graphite.**
3. **[confirm — order]** sonicate and/or let cool.
4. **Blend** **[confirm — homogenize vs granulate]**.
5. **Cast into dog-bone moulds.**
6. **Test conductivity.**
> Either route yields composites + dog-bones + conductivity data → **the poster works with or without the printer.**

## Characterization
- **Conductivity** across the dog-bone gauge length (4-point probe is the standard method — cf. Yuk 2020, Methods, p.7).
- Dog-bone = standard tensile specimen; mechanical testing possible too **[confirm if in scope]**.
- **Key figure: conductivity vs graphite %** (the percolation plot).

## Deliverable timeline
- **Now → poster:** 5 compositions, dog-bones, conductivity-vs-loading + percolation plot.
- **Later → paper.**

## Open questions for Nick
1. Exact ratios + wt% vs vol%.
2. Conductor: graphite only, or graphite + PANI?
3. Fallback step order (melt / mix / sonicate / cool / blend).
4. What the blender step is for.
5. Mechanical (tensile) testing in scope?

## Vocabulary
- **Solvent casting · melt compounding · percolation threshold · sonication · dog-bone.**

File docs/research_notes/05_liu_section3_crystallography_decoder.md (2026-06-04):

# Liu 2018, Section 3 — Plain English (crystallography decoder)

*For reading the hard part of Liu et al. 2018 (Macromol. Mater. Eng. 303, 1700494). This is grad-level synchrotron-XRD crystallography — you only need the gist. Save the deep version for the Drakes session.*

## What Section 3 actually says (one sentence)
As PCL is pushed through the nozzle and cools, (1) **more of it turns crystalline** (peaks grow) and (2) **the crystals line up with the flow direction** (rings → arcs). Printing both *increases* and *orients* the crystal structure — driven by cooling and the shear of extrusion (Liu 2018, Sect.3, p.4–5). Everything else is evidence for those two claims.

## What XRD does (the missing context)
Shine X-rays at the material; they bounce off the neatly-stacked atom rows inside *crystalline* regions and form a pattern. The pattern reveals: the crystal structure, *how much* crystal there is, and *which way crystals point*. Amorphous (tangled) material makes no sharp pattern, so XRD only "sees" the ordered part. PCL is **semi-crystalline** — part ordered, part tangled.

## Terms, decoded
- **(020), (120) "reflections" / "orthorhombic"** — a crystal is atoms in a repeating 3D grid; "orthorhombic" = the shoebox shape of that repeating unit. (020)/(120) are labels for two specific atomic planes, each making a peak. ("PCL makes two characteristic peaks.")
- **2θ (Bragg angle)** — the angle where a peak appears; encodes the spacing of those planes. X-axis of the 1D plot (Liu 2018, Fig.4b).
- **Debye–Scherrer ring → arc (key one)** — random crystals = full **ring**; aligned crystals = short **arc**. Liu sees arcs → crystals aligned → **anisotropic** (direction-dependent) (Liu 2018, Sect.3.1, p.4).
- **azimuthal angle / arc length** — the angle *around* the ring; short arc = tightly aligned, longer arc = orientation spreading.
- **integrated intensity / area under peak** — bigger area = *more* crystal. Peaks grow down the nozzle = more crystal forming (Liu 2018, Sect.3.2, p.4–5).
- **c-axis / fiber axis / drawing direction** — crystals have internal directions; "drawing direction" = the way material is pulled/extruded. Crystals line up with the flow (like pulling taffy) (Liu 2018, Sect.3.2, p.5).
- **nucleation / undercooling** — crystals start as seeds (nucleation); cooling below the melt point (undercooling) triggers them.
- **shear field / short step stress** — the drag as material squeezes through the nozzle (fast center, slow walls) plus the sudden squeeze on entry; both help crystals form and align (Liu 2018, Sect.3.2, p.5).
- **spherulites (Sect.2)** — spherical crystal clusters in the raw pellet ("Maltese cross"); after printing they shrink ~40 µm → <4 µm — smaller, more numerous crystals (Liu 2018, Fig.2, p.2–3).

## What you actually need
You do NOT need to master XRD. The transferable lesson: **how you print changes the internal crystal structure, which changes mechanical behavior** — that's why printed PCL came out brittle (printing raised + oriented crystallinity). Everything about crystal axes / Debye rings = skim, revisit with Drakes.

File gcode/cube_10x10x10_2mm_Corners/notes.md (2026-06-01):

# Part: cube_10x10x10_2mm_Corners

A 10×10×10 mm cube with reinforced corners (2 mm chamfers / fillets). Calibration geometry.

## Source

- **STL:** `source.stl` (original from lab, dated October 2024)
- CAD source (.f3d / .step) not yet committed — TODO: ask Nick for it.

## Files in this folder

| File | What it is |
|---|---|
| `source.stl` | Original 3D mesh |
| `original_BROKEN.gcode` | PrusaSlicer 2.9.2 output from 2026-06-01. Has the sticky-F bug (only F1500 in entire file → travel = print = 25 mm/s). Kept for reference. |
| `travel_fixed.gcode` | Hand-patched by `scripts/patch_travel_speed.py`. Travel moves now at F3600 (60 mm/s), print moves at F1500 (25 mm/s). |
| `notes.md` | This file. |

## Print info (PrusaSlicer 2.9.2)

- **Profile used:** `configs/prusaslicer/print/PCL_DIW_25print_25travel_BROKEN.ini` (original) → `PCL_DIW_25print_60travel_FIXED.ini` (corrected)
- **Filament profile:** `ABS-30M_240C_80Cbed.ini` — note this is mismatched with PCL DIW (see repo README "Known issues")
- **Printer profile:** `30M-ESR_T1_Heated.ini`
- **Layer height:** 0.25 mm
- **Extrusion width:** 0.38 mm
- **Perimeters:** 4
- **Infill:** 100%
- **First-layer Z-offset:** Default (TBD — possibly needs tuning per Day 1 beading observation)

## Observations

- 2026-06-01 (Day 1): Print exhibited stringing during travel between separated paths. Diagnosed as sticky-F bug. See `runs/2026-06-01_day1_travel_speed_diagnosis/notes.md`.

## TODOs

- [ ] Print with `travel_fixed.gcode` and compare visual quality side-by-side with original.
- [ ] Tune first-layer Z-offset for beading (Nick's Day 1 fix #1).
- [ ] Replace ABS filament profile with PCL-appropriate one.
- [ ] Consider adding 1–3 mm retraction (currently `retract_length = 0`).

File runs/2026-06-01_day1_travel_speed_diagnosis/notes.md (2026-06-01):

# Run: Day 1 — travel speed diagnosis

**Date:** 2026-06-01
**Operator:** Nengi
**Goal:** Diagnose why the lab's calibration cube print showed stringing/oozing during travel moves.

## Setup

- **STL:** `gcode/cube_10x10x10_2mm_Corners/source.stl`
- **Material loaded in syringe:** TBD (asked Nick to confirm — probably PCL solution or vaseline-like test ink, not actual ABS despite the filament profile)
- **Reservoir head:** TBD (likely SDS-10 for DIW)
- **Nozzle gauge / diameter:** TBD — slicer profile says 0.5 mm nozzle diameter
- **Print profile used:** `Print settings_0.35w, 0.25z, 25f, 100%.ini` (saved as `settings/print_25travel_BROKEN.ini`)
- **Filament profile used:** `filament settings_240°C, 25%Fan, 80°CBed (ABS-30M).ini` (saved as `settings/filament_ABS-30M_240C.ini`)
- **Printer profile used:** `30M-ESR_T1_Heated.ini` (saved as `settings/printer_30M-ESR_T1_Heated.ini`)
- **Settings snapshot:** `settings/` (this folder)

## Key parameters (TL;DR)

| Parameter | Value |
|---|---|
| Layer height | 0.25 mm |
| Print speed | 25 mm/s (F1500) |
| **Travel speed** | **25 mm/s (F1500) — BUG** |
| Extruder temp | 240 °C (profile mismatch — see Observations) |
| Bed temp | 80 °C (profile mismatch) |
| Extrusion multiplier | 1.0 |
| Retraction length / speed | 0 mm @ 40 mm/s (effectively no retraction) |
| Z-hop | 0 mm |

## Result

- [x] Stringing between paths
- [ ] Clean print
- [ ] Blobs at perimeter start/end
- [ ] Inconsistent line width
- [ ] Gaps in perimeters

**Photos:** `photos/` — empty for now, planned for Day 2 once we run the fixed file alongside.

## Diagnosis / interpretation

Ran `scripts/analyze_gcode.py` on `original_BROKEN.gcode`:

| Measurement | Value |
|---|---|
| Total lines | 7,013 |
| Travel-only moves (G1 X Y, no E) | 242 |
| Print moves (G1 X Y with E) | 5,732 |
| Unique F values | **F1500 only** (= 25 mm/s) |

**Root cause:** The print profile has every speed set to 25 mm/s. PrusaSlicer only emits a new `F` value when the speed actually changes between moves, so it wrote F1500 once on the very first move and never wrote another F. Every subsequent move — print and travel alike — inherited that 25 mm/s.

Conclusion: travel was crawling at the same speed as print, giving the ink plenty of time to ooze during repositioning.

**Fix:** Change `travel_speed = 25` → `travel_speed = 60` in the print profile (saved as `configs/prusaslicer/print/PCL_DIW_25print_60travel_FIXED.ini`) and re-slice. As a backup, hand-patched the existing G-code using `scripts/patch_travel_speed.py` (242 travel moves now F3600 = 60 mm/s, 202 print re-entries restamped F1500 = 25 mm/s). The patched file is at `gcode/cube_10x10x10_2mm_Corners/travel_fixed.gcode`.

**Why 60 mm/s:** Zhang 2021 and the DIW literature recommend travel = 3–10× print speed. With 25 mm/s print, 60 mm/s is the conservative middle of the recommended 30–80 mm/s range.

## Side observations (didn't act on these yet)

1. The **filament profile is for ABS at 240 °C with an 80 °C bed.** We're doing PCL via DIW at room temperature — the temps in the profile are meaningless for our actual setup, or the configs need to be updated. Need to confirm with Nick.
2. **Retraction is 0** on all five extruders in the printer profile. After we run the travel-speed-fixed print, if there's still any stringing, that's the next thing to tune (1–3 mm typical).
3. There's an `M756 S0.25` command emitted at every single layer change. Not wrong, just chatty — could be stripped if it bothers Repetrel.

## Next change to try

Print the `travel_fixed.gcode` (or re-slice with the fixed INI) and compare result side-by-side with the original print. If still stringing → add `retract_length = 1.5` to the printer profile. If clean → bump `travel_speed` to 80 mm/s and re-test.

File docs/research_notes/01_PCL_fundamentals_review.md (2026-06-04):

# PCL Review — Summary & Notes

**Paper:** Woodruff, M. A. & Hutmacher, D. W. (2010). *The return of a forgotten polymer — Polycaprolactone in the 21st century.* Progress in Polymer Science, 35, 1217–1256.
**Why you're reading it:** foundational "what is PCL and why do we use it" — feeds your polymer class and your poster. The *paper* frames PCL for tissue engineering, but for **your** project the takeaway is PCL's **flexibility + processability** as a substrate for **flexible electronics**. (The bone/scaffold content is background — your live application is a flexible *conductive* composite.)

*Citations below: (Woodruff 2010, location) unless noted. Page numbers are the journal page on the PDF.*

---

## The story in one paragraph
PCL was synthesized way back (Carothers group, ~1930s) and was popular for drug delivery in the 1970s–80s. It got **"forgotten" for ~two decades** because faster-degrading polymers (PLA, PGA, PLGA) were preferred — PCL's slow 2–4 year degradation looked like a disadvantage. It came *back* with **tissue engineering** in the 1990s–2000s, thanks to easy processing, low cost, and FDA approval (Woodruff 2010, Abstract & Intro, p.1218). *(For your project, the inheritance isn't the degradation — it's that PCL is cheap, processable, and flexible.)*

---

## Key properties — the numbers to actually know *(all from Woodruff 2010, Sect.2, p.3 unless noted)*
- **Made by:** ring-opening polymerization (ROP) of ε-caprolactone (Woodruff 2010, Sect.2, p.1218).
- **Type:** hydrophobic, **semi-crystalline** aliphatic polyester (Woodruff 2010, p.3).
- **Glass transition (Tg): −60 °C** → at room temp PCL is above Tg, so it's **soft/rubbery, not glassy** ← *the key property for your project* (Woodruff 2010, p.3).
- **Melting point (Tm): ~59–64 °C** (Woodruff 2010, p.3). *(Liu 2018 lists 58–60 °C for Mw 50k — Liu 2018, Sect.2.2, p.2.)*
- **Molecular weight range:** ~**3,000 to 80,000 g/mol**; **crystallinity decreases as MW increases** (Woodruff 2010, p.3).
- **Solubility:** dissolves well in **chloroform, DCM**; **poor in acetone**; insoluble in alcohols (Woodruff 2010, p.3). *(Borne out in DIW: DCM ink works, acetone underperforms — Zhang 2021, Sect.3.1.2, p.6.)*
- **Blend-friendly:** mixes/copolymerizes easily and accepts fillers (Woodruff 2010, p.3–4).

---

## How and why it degrades *(core PCL knowledge; less central to electronics)*
- **Total degradation 2–4 years**, slower at higher MW (Woodruff 2010, Sect.3, p.4).
- **Two stages:** hydrolysis of ester bonds → MW drops; then intracellular uptake once MW < ~3,000 (Woodruff 2010, Sect.3, p.5).
- **Mass loss begins ~MW 5,000** (~9 months in vivo) (Woodruff 2010, Fig.4, p.7).
- Final product **6-hydroxylcaproic acid** enters the citric acid cycle (Woodruff 2010, Fig.5, p.8).
- **Degrades without an acidic burst** (unlike PLA/PGA) → low inflammation (Woodruff 2010, Sect.3, p.4).

---

## Why PCL — and why you composite it (the core of your project)
- PCL is **flexible and easy to process** (above its Tg of −60 °C at room temp; melts/dissolves easily) — ideal for a *flexible* electronic substrate.
- **BUT pure PCL is an electrical insulator** — all single bonds, electrons locked. *(General polymer fact, not from a specific paper in your set.)*
- **Fix: composite it.** Add a conductor — **graphite/carbon** filler, or an intrinsically conducting polymer like **polyaniline (PANI)**. The conductor brings conductivity; PCL brings flexibility + processability. *(PEDOT:PSS is the published parallel — Yuk 2020.)*
- Same composite logic as the old bone plan (add a mineral for stiffness/osteoconductivity, e.g. mPCL + 20 wt% β-TCP — Woodruff 2010, Sect.8.2, p.24–25); here you add a conductor instead.

## What makes a good flexible conductor (criteria — straight into your poster)
1. **A percolating conductive network** — enough conductor, connected, for a continuous current path. *(General concept — cite the graphite-composite paper, not in this set.)*
2. **Flexibility retained** — enough PCL matrix that it stays bendable, not brittle.
3. **Uniform filler dispersion** — even spread (sonication) for consistent conductivity.
4. **Stable conductivity under flexing** — keeps conducting when bent/cycled, doesn't crack the network. (Cf. **Yuk 2020, p.4, Fig.3b–c**: <5% conductivity drop over 10,000 bends.)
> Golden rule: target just above the percolation threshold — minimum conductor for maximum flexibility/printability.

## Where YOUR method fits
- Fabrication menu (solvent casting, melt extrusion, direct writing) is material-agnostic (Woodruff 2010, Sect.8.1, Fig.9 — see note 03).
- Your routes: melt-compound + extrude/3D-print, or solvent-cast / mould-cast.
- **Key flip from the scaffold version:** a scaffold *wants* porosity; a **conductor wants a dense, continuous composite** — pores break the network. Aim for dense, well-dispersed dog-bones.

---

## ✍️ Things to write down (the keepers)

**For the polymers class (Drakes):**
- PCL = semi-crystalline aliphatic polyester via **ROP of ε-caprolactone**; **Tg −60 °C, Tm ≈ 60 °C**; crystallinity drops as MW rises (Woodruff 2010, Sect.2, p.3).
- Higher MW → higher viscosity, harder to melt, slower degradation.
- PCL alone is an **insulator**; conduction needs an added filler or conjugated polymer.

**For the poster Intro / Significance:**
- "PCL is flexible, processable, biocompatible, FDA-familiar — a strong substrate for flexible devices" (Woodruff 2010, Abstract).
- "Pure PCL is an insulator, so a conductor (graphite and/or PANI) is added → a flexible conductive composite."

**For your research understanding:**
- Solubility (chloroform/DCM yes, acetone weak) → the solvent-cast route (Woodruff 2010, p.3; Zhang 2021, Sect.3.1.2, p.6).
- The percolation threshold is the variable your experiment maps *(cite the composite paper)*.
- PCL's flexibility (Tg −60 °C) is why it's the substrate.

---

## Parked for later
- **Liu et al. 2018 (PCL melt-extrusion crystallinity / XRD)** — revisit after the polymers session with Drakes (crystals align in flow, volume fraction rises down the nozzle — Liu 2018, Sect.3, p.4–5).

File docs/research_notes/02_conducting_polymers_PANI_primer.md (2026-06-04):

# Conducting Polymers & Polyaniline (PANI) — Primer

*Background for the flexible-electronics pivot, built on your EE intuition.*

> **Citation note:** the conducting-polymer fundamentals here (conjugation, doping, PANI's oxidation states) are **general/textbook knowledge** — they are *not* from any one paper in your set, so they don't carry a paper citation. The only paper-specific citations are to **Yuk 2020** for the PEDOT:PSS numbers, since that's the conducting-polymer paper you actually have.

---

## 1. Why most polymers insulate, but some conduct
- **Normal polymers (PCL):** all single (sigma) bonds → electrons locked → **insulator.**
- **Conducting (conjugated) polymers:** **alternating single and double bonds** along the backbone — that alternation is the key. *(General.)*

## 2. Conjugation = the "electron cloud"
- Double bonds carry **pi electrons**; when bonds alternate, the p-orbitals overlap continuously and the pi electrons **delocalize into a continuous cloud** along the chain. That's the "electron cloud." *(General.)*

## 3. Conjugation isn't enough — you DOPE it
- A bare conjugated polymer behaves like a **semiconductor** (has a band gap), like silicon.
- **Doping** adds carriers — like doping silicon. Carriers are **polarons/bipolarons** moving along the chain. Conductivity can jump ~10 orders of magnitude. *(General.)*

## 4. Polyaniline (PANI) specifically *(general/textbook)*
**Structure:** benzene rings linked by nitrogen — the single/double-bond diagram your mentor showed.

| State | Oxidation | Conducts? |
|---|---|---|
| Leucoemeraldine | fully **reduced** | no |
| **Emeraldine** | **half-oxidized** | **only when doped** ← the useful one |
| Pernigraniline | fully **oxidized** | no |

**PANI's special trick — acid doping:** protonate **emeraldine base** (insulating) with acid → **emeraldine salt** (conductive). Add base → off again. A reversible acid/base ON–OFF switch.

## 5. Why not PANI alone — why PCL or graphite
- PANI alone is **brittle and hard to process** (intractable). *(General.)*
- **PCL is flexible + processable** but insulating. Combine → flexible conductive composite. *(PEDOT:PSS is the published demonstration of this combine-conductor-with-processability idea — Yuk 2020.)*

## 6. How it maps to your project
- **PCL** = flexible insulating matrix/substrate.
- **PANI** = intrinsically conducting polymer (conjugation + acid doping). *(General.)*
- **Graphite** = conductive filler; conducts past the **percolation threshold**. *(General concept — cite your graphite-composite paper.)*
- **Yuk 2020** is your closest *published* precedent for printing a conductor (PEDOT:PSS). Read it with this primer in hand. Concrete benchmarks to expect from a printed conductor:
  - Conductivity **155 S/cm (dry), 28 S/cm (hydrogel)** — (Yuk 2020, p.4, Fig.3a).
  - **<5% conductivity drop over 10,000 bends** — (Yuk 2020, p.4, Fig.3c).
  - Printable ink window **5–7 wt%** nanofibrils — (Yuk 2020, p.2, Fig.1).
  - Conductivity arises after drying/annealing drives **percolation among the nanofibrils** — (Yuk 2020, p.2 & Methods p.6–7).

---

## Vocabulary to lock in *(all general terms)*
- **Conjugation** — alternating single/double bonds → delocalized pi electrons.
- **Delocalized π-electron cloud** — the conduction highway.
- **Doping** — add/remove electrons (PANI: protonate with acid) to create carriers.
- **Polaron / bipolaron** — the mobile carriers.
- **Emeraldine base vs salt** — PANI insulating vs conductive; acid converts base → salt.
- **Intrinsically conducting polymer (ICP)** — conducts on its own backbone (PANI, PEDOT) vs a filler composite (PCL + graphite).
- **Percolation threshold** — filler loading where a composite switches conductive *(cite composite paper)*.

## One-line summary
**Conjugation builds the electron highway; doping puts cars on it. PANI's highway switches on with acid. PCL bends but can't conduct — pair them (or load PCL with graphite) for flexible + conductive.**

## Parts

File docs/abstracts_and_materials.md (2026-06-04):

# Abstracts + Materials — Reading Orientation (5 papers)

*Plain-English summaries (not the original text — paraphrased to respect copyright). Each entry says **where to read the real thing** in your PDF. Read the actual abstract + the lead-in before the methods, as your mentor said — this just orients you first.*

*Open-access (free to grab the PDF): Zhang, Yuk, Teixeira. Paywalled: Liu, Woodruff.*

---

# PAPER 1 — Liu et al. 2018 (melt-extrusion 3D printing of PCL) · *Macromol. Mater. Eng. 303, 1700494*

### Abstract — plain words *(p.1, top)*
They built a **screw-assisted melt-extrusion** printer and used **in-situ synchrotron XRD** to watch PCL's crystal structure form *as it printed*. Result: extrusion drives a strong **directional (anisotropic) crystal alignment** — a step toward printing parts that mimic natural tissue's directional structure.

### Lead-in before methods *(end of Section 1, p.1–2)*
Crystallinity/orientation strongly affect scaffold properties and cell behavior, and MW affects how PCL crystallizes — but how structure develops *during* printing is rarely studied. So this is one of the first in-situ looks at it.

### Materials & methods *(Section 2, "Experimental," p.2–4)*
Screw-assisted extruder (PABS): PCL melts in a heated chamber, compressed air (~6 bar) feeds a stepper-driven screw, **0.5 mm nozzle**, **10 rpm / 110 °C → 0.1 mm/s**. Material: PCL **CAPA6500, Mw ≈ 50,000**, Tm 58–60 °C, Tg −60 °C. Tracked by in-situ synchrotron XRD.

---

# PAPER 2 — Woodruff & Hutmacher 2010 (PCL review) · *Prog. Polym. Sci. 35, 1217–1256*

### Abstract — plain words *(p.1, "Abstract")*
PCL was big in 1970s–80s drug delivery, fell out of favor for ~two decades (faster-degrading polymers preferred), then returned with tissue engineering thanks to its easy processing, low cost, and FDA approval — good for long-term degradable implants. The review surveys PCL in medical devices, drug delivery, and tissue engineering.

### "Text before the methods"?
**It's a review — no methods section.** The closest "preparation" content is **Section 8.1 (Scaffold fabrication)**, already in your `printing_and_preparation` note. Read the abstract; don't hunt for methods.

---

# PAPER 3 — Zhang et al. 2021 (DIW of PCL/PEO) · *Prog. Nat. Sci. Mater. Int. 31, 180–191*

### Abstract — plain words *(p.1, top)*
DIW deposits material at room temperature (good for heat-sensitive ingredients), but the ink needs the right flow behavior — so most work used water-based hydrogels, leaving water-insoluble PCL under-explored. They made DIW inks by dissolving PCL in **DCM** and **acetone**, added **PEO** for hydrophilicity, and studied how solvent + composition change the rheology. Printed woodpile constructs; solvent strongly affected surface, and PEO raised roughness/wettability. Bottom line: DIW can process hydrophobic polymers.

### Lead-in before methods *(end of Section 1, p.2)*
States the **three DIW ink rules**: (1) shear-thinning, (2) extrudes as a clean filament, (3) recovers **>80%** of viscosity after deposition. Notes PCL/PEO hadn't been DIW-printed; aims = study the rheology, the solvent/PEO surface effects, and DIW's usefulness as a tool.

### Materials & methods *(Section 2, p.2–4)*
- **Materials:** PCL **Mn ~80,000**; PEO Mn ~200,000 (Sigma); solvents DCM + acetone (ACE).
- **Ink prep:** dissolve PCL (200 rpm, 35 °C, 2 h) at **7.5% (low) and 15% (high) w/w**; PCL:PEO 1:1. Manual dispense through a **24G nozzle**.
- **Rheology:** shear-viscosity sweeps, oscillatory yield-stress sweep, and a **creep-recovery test** (the >80%-at-90s screen).
- **Printing:** desktop DIW rig built from a Prusa i3 FDM + syringe extruder; 5-layer woodpile, 311 µm filament; speed 2.5–12.5 mm/s, flow 0.48–1.44 mm³/s. Plus SEM, profilometry, XRD, XPS, TGA/DSC, contact angle.
- **Headline:** **DCM ink recovered ~93% (passes); acetone <80% (fails) → DCM preferred.** Best fidelity ≈ 5 mm/s + 0.48 mm³/s.

---

# PAPER 4 — Yuk et al. 2020 (3D printing of conducting polymers) · *Nat. Commun. 11, 1604*

### Abstract — plain words *(p.1, top)*
Conducting polymers are promising for energy storage, flexible electronics, and bioelectronics, but conventional fabrication (inkjet, screen printing, e-beam litho) has real limits. They make a high-performance **3D-printable PEDOT:PSS ink** that prints high-resolution, high-aspect-ratio structures, integrates with other materials (insulating elastomers) in multi-material printing, and converts to a soft conductive **hydrogel**. Demo: a soft neural probe recording in a live mouse.

### Note on structure (where the methods live)
**Nature format:** Abstract → Intro → **Results** → Discussion → **Methods at the very END (p.6–7).** No "intro paragraph right before methods" like the others — read the **abstract + intro** for the *why*, then the **Methods** at the end for materials.

### Materials & methods *("Methods," p.6–7)*
- **Ink prep:** commercial PEDOT:PSS → freeze in liquid N₂ → freeze-dry to isolate nanofibrils → re-disperse in **water:DMSO 85:15** → homogenize. Printable window **5–7 wt%** (below = spreads, above = clogs).
- **Printing:** custom Cartesian printer, nozzles **200/100/50/30 µm**; after printing **dry 60 °C, anneal 130 °C** → solid conductor; swell in PBS → hydrogel.
- **Characterization:** SEM/TEM, SAXS, rheology, AFM nanoindentation, **4-point-probe conductivity**, CV/EIS, in-vivo recording.
- **Headline numbers:** **155 S/cm dry, 28 S/cm hydrogel**; **<5% conductivity change over 10,000 bends**; modulus 1.5 GPa dry vs 1.1 MPa hydrogel.

---

# PAPER 5 — Teixeira et al. 2026 (agarose parameter optimization) · *MRS Commun. 16, 212–218*

### Abstract — plain words *(p.1, top)*
A **method paper**. They optimized agarose's 3D-printing parameters and showed it's printable. Best line accuracy **97.3%** at **2% agarose, 25G, 6 mm/s, 40 kPa**. Adding **3% laponite** raised grid accuracy to **>83%**. Then they printed a scaffold. The method works for any shear-thinning material.

### Lead-in before methods *(end of Introduction, p.2)*
Agarose is biocompatible, shear-thinning, high-melting (~95 °C), tissue-mimicking. They extend Webb et al.'s parameter-optimization method (vary gauge, speed, pressure) by scoring accuracy from printed **area**, not just line thickness. Key for you: **the method is material-agnostic — works for any shear-thinning ink.**

### Materials & methods *("Materials and methods," p.2–3)*
- **Solution:** agarose in water at 1–5% w/v; held at print head at **40 °C**; viscosity on a rheometer (0.1–100 s⁻¹).
- **The method itself (what your mentor likely wants):** print an **alternating S-line**, scan it, measure deviation from CAD in **ImageJ**; toss lines missing >20% material; compute accuracy from **area**. Then print a **grid** and score **pore printability Pr = L²/16A** (Pr = 1 = perfect square pore).
- **Parameters swept:** speed **1–10 mm/s**, pressure **40–100 kPa**, gauge **25G/27G/30G**, across concentrations.
- **Headline:** sweet spot 2% / 25G / 6 mm/s / 40 kPa; laponite lifted grid accuracy ~60% → ~83%.

---

# Where they OVERLAP (don't read the same thing five times)
- **Extrusion/DIW rheology is the shared backbone.** Zhang states the three ink rules (shear-thinning, clean filament, >80% recovery); Teixeira and Yuk rely on the same shear-thinning behavior. Learn it once.
- **The "find the printing-parameter window" method** is shared by **Zhang** (fidelity vs speed/flow) and **Teixeira** (accuracy vs speed/pressure/gauge, via ImageJ). Teixeira is the cleanest standalone recipe.
- **PCL fundamentals** (semicrystalline, Tm ~60, Tg −60) appear in Liu, Woodruff, and Zhang — once.
- **Tissue-engineering framing** is in all except **Yuk** (flexible electronics / bioelectronics).

# What's UNIQUE to each (read for the differences)
- **Liu** — what melt extrusion does to PCL crystallinity.
- **Woodruff** — broad PCL map (properties, degradation, applications); no methods.
- **Zhang** — how to make a *DIW ink from PCL* with solvents; **DCM beats acetone.** Your closest precedent for solvent-route PCL DIW.
- **Yuk** — how to print a *conductor* (PEDOT:PSS), make it flexible/hydrogel, and hold conductivity through 10,000 bends. **Your closest precedent for the flexible-electronics goal.**
- **Teixeira** — the *method to optimize* any shear-thinning ink's parameters. Directly usable on your composite.

# For your project (flexible conductive PCL + graphite)
- **Yuk = north star** (printing a conductor; flexibility under bending; percolation via dry-annealing).
- **Zhang = your PCL-DIW how-to** if you go the solvent route (and confirms DCM > acetone).
- **Teixeira = the parameter-optimization playbook** for whatever ink you settle on.
- **Liu + Woodruff = PCL background.**

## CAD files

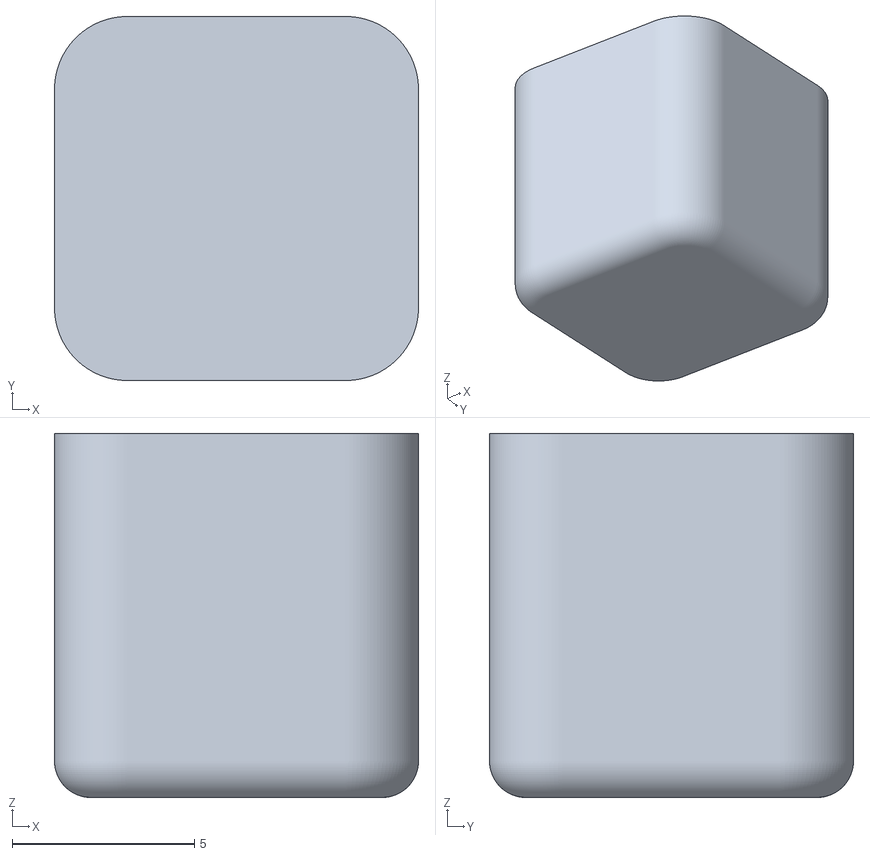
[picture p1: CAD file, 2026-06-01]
gcode/cube_10x10x10_2mm_Corners/source.stl
10.00 x 10.0 x 10.0

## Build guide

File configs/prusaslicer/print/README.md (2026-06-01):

# Print profiles

Naming convention: `<material>_<process>_<print_speed>print_<travel_speed>travel_<status>.ini`

| File | What it is | Status |
|---|---|---|
| `PCL_DIW_25print_25travel_BROKEN.ini` | Original lab profile from 2021. Every speed set to 25 mm/s, which triggers PrusaSlicer's sticky-F bug — only F1500 is emitted in the resulting G-code. **Kept here for reference, do NOT use for new prints.** |
| `PCL_DIW_25print_60travel_FIXED.ini` | Corrected version: `travel_speed = 60` (was 25). All other settings identical. Re-slice with this. | **Current default** |

## Why two profiles instead of one in-place fix?

Keeping the broken one preserves history. Anyone looking at the repo a year from now will see *both* the bug and the fix and understand what changed. The git log already shows the diff, but having both files explicitly named makes the "tribal knowledge" visible without having to read commits.

## When to make a new profile

Whenever you're going to change settings *in a way you want to be repeatable*. Don't edit a checked-in profile in-place except to fix an outright mistake. Copy it, rename it with the changed parameter in the filename, and commit.

Examples of new profiles you might add:
- `PCL_DIW_15print_60travel_FIXED.ini` — slower print speed for thicker ink
- `PCL_DIW_25print_80travel_FIXED.ini` — faster travel for stringy ink
- `PCLPEO_DIW_5print_30travel_v1.ini` — completely different ink, slower print

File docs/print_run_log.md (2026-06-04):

# Print Run Log — PCL / Hyrel 30M

**How to use this (the whole trick):**
1. **One row per print attempt.** Even failed ones — *especially* failed ones.
2. **Change ONE thing per run** when you can. The "What I changed" column is the experiment.
3. **Always fill "Result" and snap a photo.** Name the photo `runNN_date.jpg` and put the name in the Photo column. A photo with no log entry is useless; a log entry with no photo is half-useless.
4. At the end of the day, the rows you marked **KEEP** are your poster's Results section.

If you only ever fill three columns, make them: **What I changed · What happened · Keep/Toss.**

---

## The log

| Run | Date | Material (PCL Mw / what's in syringe) | Nozzle (gauge) | Extruder temp (°C) | Pulse time | Print speed | Travel speed | **What I changed (one thing)** | **What happened** | Photo | Keep / Toss / Next |
|----|---|---|---|---|---|---|---|---|---|---|---|
| 01 | _ex_ 2026-06-02 | PCL Mw ~80k | unknown — MEASURE | 90 | (value) | 6 mm/s | 6 mm/s | baseline, nothing | low stability, pooled | run01_0602.jpg | Next: ID nozzle |
| 02 |  |  |  |  |  |  |  |  |  |  |  |
| 03 |  |  |  |  |  |  |  |  |  |  |  |
| 04 |  |  |  |  |  |  |  |  |  |  |  |
| 05 |  |  |  |  |  |  |  |  |  |  |  |
| 06 |  |  |  |  |  |  |  |  |  |  |  |
| 07 |  |  |  |  |  |  |  |  |  |  |  |
| 08 |  |  |  |  |  |  |  |  |  |  |  |

---

## Things to capture once (not every run)

- **Nozzle gauge** — currently unknown. Measure the inner diameter or read the hub. This is run-blocking; do it first.
- **Material identity** — exact PCL Mw, and what (if anything) is mixed in (CaCO₃ / ground bone / HAp, and %).
- **What "pulse time" actually controls on this head** — ask Nick, write the answer here so you stop guessing:
  > _pulse time = ______________________________ (units: ____, raise it when: ____)_
- **Repetrel screenshot** of the working parameter set once you get a clean print — that's your "Printing Parameters" poster panel.

## Day-end habit (2 minutes)
Pick the single best print of the day, photograph it next to a ruler/scale, and write one sentence: *"Changing X from ___ to ___ did ___."* That sentence is a poster bullet.

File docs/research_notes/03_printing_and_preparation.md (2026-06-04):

# Printing & Preparation — Separate Summaries

Two papers, kept separate, focused on the **printing / preparation** content. Methods apply whether printing a scaffold or a flexible PCL/PANI substrate.

*Citations: (Author Year, location).*

---

# PAPER 1 — "Return of a forgotten polymer" (Woodruff & Hutmacher 2010)
### → the printing/preparation portion = **Section 8.1, "Scaffold fabrication"** (Woodruff 2010, p.15–24)

"Printing" isn't in the heading, which is why it's hard to find. Methods are grouped as:

**8.1.1 Conventional** *(Woodruff 2010, Sect.8.1.1)*
- **Porogen / particulate leaching** — template dissolved out to leave pores; ~5–100 µm, porosity <90%; random connectivity (Woodruff 2010, Fig.9).
- **Phase separation (TIPS)** — cool a polymer solution to split into solid + pore regions; porosity <70% (Woodruff 2010, Fig.9).
- **Gas foaming / supercritical CO₂** — solvent-free pores.

**8.1.2 Textile / fiber** *(Woodruff 2010, Sect.8.1.2)*
- **Electrospinning** — high-voltage sub-micron fibers; porosity 90–95%; PCL is the most common polymer here.

**8.1.3 Solid Free-Form Fabrication = the 3D-printing family** *(Woodruff 2010, Sect.8.1.3)* ← *your part*
- **SLA / SLS / 3DP** — laser/binder methods.
- **8.1.3.2 Extrusion / Direct Writing** *(Woodruff 2010, Sect.8.1.3.2)* — closest to your work:
  - **FDM:** heated liquefier extrudes melt layer-by-layer; pore ~100–2000 µm (Woodruff 2010, Fig.9).
  - **PED:** extrudes **pellets directly**, no filament prep.
  - **Direct Writing (DIW):** extrudes **pastes/inks**; pore ~5–100 µm (Woodruff 2010, Fig.9).
  - **Limitation:** single extrusion head → pore openings differ in z vs x–y (Woodruff 2010, Sect.8.1.3.2).

**Solvent note:** in solvent-based 3DP, **warping scales with solvent vapor pressure** — chloroform (low) → little warping; DCM → more (Woodruff 2010, Sect.8.1.3.1.4 / 3DP).

**4 scaffold-design criteria:** interconnected porosity · matched biodegradation · cell-friendly surface · matched mechanics (Woodruff 2010, Sect.8, p.15–16).

---

# PAPER 2 — "Structural Evolution of PCL during Melt Extrusion 3D Printing" (Liu et al. 2018)
### → this paper *is* the printing/preparation paper

**What it's about:** 3D-printed PCL by **screw-assisted melt extrusion**, watched with **in-situ synchrotron XRD** as it printed (Liu 2018, Abstract & Sect.2.3).

**The printing setup (the "preparation" part) — (Liu 2018, Sect.2.1, p.2):**
- Screw-assisted extruder (PABS): PCL melts in a heated chamber, **compressed air (~6 bar)** feeds a stepper-driven screw, **0.5 mm nozzle**.
- Conditions: **10 rpm screw / 110 °C → 0.1 mm/s** print speed.
- Material: PCL **CAPA6500, Mw ≈ 50,000**; Tm 58–60 °C, Tg −60 °C, density 1.1 g/cm³ (Liu 2018, Sect.2.2, p.2).
- Spherulite size: **~40 µm (pellet) → <4 µm (printed)** (Liu 2018, Fig.2, p.2–3).

**Key finding (crystallinity — save the deep dive for Drakes):**
- Shear flow **aligns PCL crystals in the flow direction** (anisotropy) (Liu 2018, Sect.3.1, p.4).
- **Crystal volume fraction increases** down the nozzle (y = 0 → 1.8 mm), driven by **undercooling + shear** (Liu 2018, Sect.3.2 & Fig.5, p.5).
- More crystallization after exit, as it cools/stretches (Liu 2018, Sect.3.2, p.5).

**One-line takeaway:** how you print changes the polymer's internal structure — temp, screw speed, nozzle size set crystallinity/orientation, which set mechanical properties (Liu 2018, Conclusions, p.5).

---

## TL;DR
- **Woodruff** = a *menu* of fabrication methods (your slice: 8.1.3.2 extrusion / direct writing).
- **Liu** = a *deep look at melt extrusion*, showing print parameters reshape crystallinity.
- **Parked:** Liu's detailed crystallography (crystal axes, XRD patterns) until after Drakes.

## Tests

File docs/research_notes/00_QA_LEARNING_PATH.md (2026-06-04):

# Q&A Learning Path — what we worked through (and the answers)

*Companion to `00_PROJECT_HANDOFF.md`. The handoff captures the project **state**; this captures the **path** — the questions Nengi actually worked through and the key answers — so the new chat knows what's already understood and doesn't re-explain it. Paste **both** into the co-op chat.*

---

## Phase 1 — G-code & the travel-speed bug
- **Q: What does F mean?** → F = **feedrate** (toolhead speed, mm/min), *not* filament/extrusion speed. It's **sticky** — only re-written when the speed changes. ÷60 for mm/s.
- **The Day-1 bug:** slicer wrote only one F (F1500 = 25 mm/s) because every speed in the INI was 25 → **travel ran at print speed → ooze/stringing.** Fix: `travel_speed` → 60 (F3600), or patch the G-code.
- **Q: Why does the E value steadily increase?** → **Absolute extrusion (M82):** E is a cumulative odometer, not per-move. Per-move amount = subtract consecutive E's. Volumetric (`M229`) → E in mm³.
- **Consequence:** in absolute mode you **can't** hand-insert `G1 E-1.5` to retract (it's an absolute target, not a pullback). Use Hyrel **M729 / M727 (unprime / prime)** — they don't touch the E odometer — or re-slice with retraction on.
- **Where unprime goes:** at the **E↔no-E boundaries** (last print move → travel → first print move). The "snail line" between circles = the **travel move** curling around because *avoid-crossing-perimeters* is enabled.
- **Q: Control unprime from PrusaSlicer?** → set `retract_length` > 0, but PrusaSlicer emits **E-retraction (`G1 E…`), not M729** — so if the lab wants M729, that's a hand-edit/post-process. Gotcha: *"only retract when crossing perimeters"* can skip retraction on clean hops. Also flagged the **240 °C temp commands** (ABS-profile leftover) to neutralize before running PCL.

## Phase 2 — Printer hardware failure
- **Q: Printer shows 1000, head won't heat, some heads missing.** → "1000" = a **temperature-sensor fault** (open thermistor reads garbage; firmware cuts heat as a *protection*, so the cold head is the safety working). Check the **E-Stop**, press the front **RESET**, check head **LEDs** (flashing = communicating), **reseat** heads; USB/COM if total comms loss. **Multiple heads down = stop and get Nick** (controller/CANBUS/power, not a setting).

## Phase 3 — PrusaSlicer learning
- Workflow: load STL → pick 3 profiles → Slice → preview → Export G-code. **Beginner mode hides travel speed & retraction → switch to Expert.** Four tabs (Plater / Print Settings / Filament / Printers); left-side gizmos (move / scale / rotate / place-on-face / measure). Sliced a test box to see the loop.

## Phase 4 — The pivot
- **Bone scaffolds → flexible electronics.** PCL becomes the flexible *substrate*; add a conductor. Learned conducting-polymer basics: **conjugation** (alternating bonds → delocalized "electron cloud"), **doping** (conceptually like doping silicon — adds carriers), **PANI** oxidation states + the **acid on/off switch** (emeraldine base → salt).

## Phase 5 — Materials understanding
- PCL fundamentals (Tg −60 °C, Tm ~60 °C, MW↔crystallinity, solubility, degradation). **Solvent casting vs melt processing.** **Percolation threshold** (enough graphite to form a connected network; target just above it to keep flexibility). **Sonication** for dispersion.

## Phase 6 — The brittleness diagnosis (a clean worked path)
- **Q: Printed PCL is brittle but the notes say "rubbery" — is it a thermoset that changed on heating?** → **No — PCL is a thermoplastic** (melts reversibly, doesn't cure/crosslink). "Rubbery" was an oversimplification: PCL is **semi-crystalline** (amorphous part = rubbery, crystalline part = rigid).
- Candidate causes weighed: printing-induced crystallinity (Liu), thin-geometry/weak fusion, or **thermal degradation**.
- **Printed at 60 °C onto a room-temp plate** → rules out degradation (60 °C is safe). With **14k → then 8k** PCL, the brittleness is mostly the **low MW itself** (few chain entanglements = brittle, and more crystalline) plus cold-plate quench → poor inter-bead fusion. ("PCL 300" flagged to confirm.)

## Phase 7 — Process / the pressure question
- **Q: Extrude (pressured) vs mould-cast (no pressure) — how does pressure affect results?** → Pressure/shear **aligns** crystals *and* graphite flakes → **anisotropic** conductivity (extrude) vs **isotropic** (cast); pressure **compacts** the network (can lower resistance); different **void** behavior (weld-lines vs trapped bubbles); the screw **mixes**. **Rule: use one route for all 5 ratios.** Cast = cleaner intrinsic baseline; extrude = closer to the real device.

## Phase 8 — Measurement & pitfalls (max-depth, all papers)
- Decided: measure **intrinsic** conductivity via multimeter on dog-bones (R → σ).
- 9 pitfalls surfaced (full detail in handoff §6): contact resistance / 4-point probe, dog-bone **geometry** (measure actual cross-section), **range** ("OL" = below percolation, not failure), graphite **settling**, **aging** drift, 8k **brittleness** handling, **nozzle size as a confound**, **clogging** at small-nozzle/high-graphite, **combinatorial blowup**.
- Key decision (handoff §7): for **intrinsic** conductivity, fix one nozzle / cast and sweep **graphite % only**; nozzle×graphite is a separate *process* study.

## Phase 9 — Papers
- Built: `abstracts_and_materials` (5 papers, PDF page locations), `source_referenced_facts` (cited), `05_liu_section3` crystallography decoder. Roles: **Yuk** = north star, **Zhang** = PCL-DIW how-to, **Teixeira** = optimization method, **Liu** = crystallinity, **Woodruff** = background.

---

## Also exists / threads
- **GitHub repo** `oinkotariah/hyrel-pcl-printing-jsnn` (gcode, configs, scripts, docs). **Nick added as collaborator.**
- **Non-research:** flight changed to go retrieve the car; **CEE&I / Shawn Johnson** + the **Dr. Curry email** action item (warm draft already written). (Dr. Curry also drew a doodle "balance the equation" puzzle — a stoichiometry gag, not project-relevant.)

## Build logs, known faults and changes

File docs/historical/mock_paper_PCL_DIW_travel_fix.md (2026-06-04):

# MOCK PAPER — annotated draft

*This is a practice fill of a research paper, built from your actual JSNN work. Each
section starts with* ***▸ What it's for*** *(plain English, so you learn the anatomy),
then the* ***Draft*** *(real text from your project). Anything in `[BRACKETS]` is a hole
you fill in later — most of them after you actually print. Don't delete the brackets
until you've replaced them with something true.*

---

## The 4-question skeleton (read this first)

A paper answers four questions, in this order. Everything else just supports them:

1. **What's the problem, and why care?** → Introduction
2. **What did you do about it?** → Methods
3. **What happened?** → Results
4. **What does it mean?** → Discussion

A poster is the *same four questions* with the words cut and the figures enlarged. So if
you can fill these, you can build the poster. Right now you can fully answer 1 and 2.
3 and 4 are waiting on your next print — and seeing that gap clearly is the job of this exercise.

---

## Title

***▸ What it's for:*** *One sentence a stranger can scan to know exactly what you did.
Specific beats clever. Name the material, the method, the machine or the finding.*

**Draft:**
> Diagnosing and Correcting Travel-Move Stringing in Direct Ink Writing of
> Polycaprolactone on a Hyrel SYSTEM 30M

*Alternatives to consider once you have results — a title can advertise the finding:*
> *A Single-Parameter Feedrate Correction Eliminates Travel Stringing in PCL Direct Ink Writing*

---

## Authors & Affiliation

***▸ What it's for:*** *Who did the work and where. Order matters — first author did the
most hands-on work; this is the authorship conversation to have with Nick.*

**Draft:**
> Onengiyeofori Inko-Tariah¹, Nick Ricks¹
> ¹IMPACT Lab, Joint School of Nanoscience and Nanoengineering (JSNN),
> North Carolina A&T State University & UNC Greensboro

---

## Abstract

***▸ What it's for:*** *A ~150–200 word miniature of the whole paper: problem → what you
did → key result → why it matters. People decide whether to read on from this alone.
Write it LAST, because you can't summarize results you don't have yet.*

**Draft (with the result left blank on purpose):**
> Direct ink writing (DIW) of polycaprolactone (PCL) enables fabrication of biodegradable
> scaffolds, but print fidelity suffers when process parameters are mismatched. During
> calibration printing on a Hyrel SYSTEM 30M, we observed persistent stringing during
> non-extruding travel moves. Analysis of the G-code revealed that the slicer
> (PrusaSlicer 2.9.2) emitted only a single feedrate (F1500, 25 mm/s) for the entire job,
> because every speed parameter was set identically; as a result, travel moves executed at
> printing speed and ink oozed between separated paths. We raised the travel speed to
> 60 mm/s (F3600) as an isolated change and evaluated its effect on stringing.
> `[RESULT — fill after printing: e.g., "stringing was reduced/eliminated, measured as ___"]`.
> `[ONE-SENTENCE SIGNIFICANCE — what this means for the lab/for PCL DIW]`. All slicer
> configurations and analysis scripts are openly released to support reproducibility.

---

## 1. Introduction

***▸ What it's for:*** *Funnel from broad to narrow: the field → the specific problem →
the gap nobody's filled → your objective (one sentence). This is where your references live.*

**Draft:**
> Direct ink writing (DIW) is an extrusion-based additive manufacturing technique in which
> a paste-like material is deposited layer by layer through a fine nozzle. It is well suited
> to soft and shear-thinning materials that cannot be processed by conventional
> melt-based 3D printing. Polycaprolactone (PCL) — a biocompatible, biodegradable,
> low-melting-point polyester — is a common DIW feedstock for tissue-engineering scaffolds
> (Zhang et al., 2021).
>
> A central challenge in DIW is **print fidelity**: keeping deposited material exactly where
> it was placed. A frequent fidelity defect is *stringing*, where ink trails across the gap
> between two separated features. Stringing is governed largely by what happens during
> *travel moves* — the non-extruding repositioning moves between printed paths — and is
> influenced by travel speed and nozzle retraction.
>
> `[GAP — state it plainly: the lab had no documented, reproducible parameter set for PCL
> DIW on the SYSTEM 30M, and a calibration print exhibited stringing of unknown cause.]`
>
> **Objective:** to diagnose the source of stringing in the calibration G-code and implement
> a minimal, reproducible correction that establishes a clean baseline for subsequent ink and
> geometry studies.

---

## 2. Materials and Methods

***▸ What it's for:*** *Enough detail that a competent stranger could repeat your work and
get the same result. This is your strongest section — be concrete. Past tense, "we did X."*

**Draft:**
>
> **2.1 Equipment.** Printing was performed on a Hyrel SYSTEM 30M equipped with a
> `[SDS-10 syringe — CONFIRM head model with Nick]` extruder in tool position T1, using a
> `[24G — CONFIRM]` nozzle. The machine was controlled via Repetrel.
>
> **2.2 Material.** `[INK FORMULATION — the real gap: PCL in which solvent (DCM/acetone)?
> what concentration? any PEO? ASK NICK what is actually in the syringe.]`
>
> **2.3 Test geometry and slicing.** A 10 × 10 × 10 mm calibration cube (`source.stl`) was
> sliced in PrusaSlicer 2.9.2 with a layer height of 0.25 mm, extrusion width 0.38 mm, and a
> nominal print speed of 25 mm/s. The Hyrel header places extrusion values in volumetric
> mode (`M229 E1 D1`), so extrusion is expressed in mm³.
>
> **2.4 G-code diagnosis.** The generated G-code (7,013 lines) was analyzed with a custom
> Python script (`analyze_gcode.py`) that counts travel moves (G1 with no E) versus print
> moves (G1 with E) and enumerates every unique feedrate (F) value. The analysis found
> 242 travel moves, 5,732 print moves, and **only one feedrate value in the entire file
> (F1500 = 25 mm/s).** Because G-code feedrate is "sticky" — once set, it carries to all
> later moves until changed — and because every speed parameter in the print profile was
> identical (25 mm/s), the slicer never emitted a second F value. Travel moves therefore
> ran at printing speed, giving ink time to ooze during repositioning.
>
> **2.5 Correction.** The travel speed was changed from 25 to 60 mm/s (a single parameter,
> `travel_speed`, in the print profile), yielding explicit F3600 on all travel moves while
> print moves remained at F1500. A hand-patch script (`patch_travel_speed.py`) reproduced
> the same result on the existing G-code without re-slicing. Following a one-variable-at-a-time
> methodology (Teixeira et al., 2026), retraction was deliberately left unchanged in this
> experiment so the effect of travel speed could be isolated.
>
> **2.6 Characterization.** `[HOW YOU'LL JUDGE THE RESULT — e.g., printed cubes were
> photographed and inter-path stringing assessed qualitatively; line width and visible
> strands quantified in ImageJ.]`
>
> **2.7 Rheological context.** PCL inks are shear-thinning: viscosity drops under the shear
> of extrusion and recovers at rest. Recovery rate controls how well a deposited line holds
> its shape (Zhang et al., 2021). `[Optional: note the qualitative vaseline demonstration of
> shear-thinning and recovery observed in the lab.]`

---

## 3. Results

***▸ What it's for:*** *What happened — facts and figures only, no interpretation yet.
Each figure gets a number and a one-line caption. THIS IS YOUR EMPTY BOX. You fill it
after you print travel_fixed. Do not write anything here you haven't observed.*

**Draft (structure only — fill after the print):**
>
> **Figure 1.** `[Side-by-side photo: original (F1500-only) cube vs. travel_fixed cube,
> same region, same scale.]`
>
> `[SENTENCE 1 — the observation, neutral: e.g., "The original print showed N visible
> strands across the gap between concentric paths; the travel-fixed print showed M."]`
>
> `[SENTENCE 2 — any measurement: line width, strand count, or "no measurable strings."]`
>
> `[If you also test retraction later, that becomes Figure 2 and its own result.]`
>
> *(Note to self: a single clean before/after photo with a scale bar is enough to make this
> section real. A number is better. Either one turns this from a plan into a finding.)*

---

## 4. Discussion

***▸ What it's for:*** *What the results MEAN. Interpret, compare to the literature, admit
limitations. This is where you're allowed to reason — but every claim must trace to a
result in Section 3.*

**Draft (conditional skeleton — fill once Results exist):**
>
> `[IF stringing dropped:]` Raising travel speed reduced the time the nozzle lingered over
> each inter-path gap, lowering ooze — consistent with travel speed being a primary lever
> for stringing in DIW. The recommended DIW travel range (≈30–80 mm/s; Zhang et al., 2021)
> brackets our 60 mm/s value.
>
> `[IF stringing persisted:]` Travel speed alone did not eliminate stringing, which is
> consistent with residual nozzle pressure: with zero retraction, ink can continue to weep
> regardless of how fast the head moves. This motivates retraction as the next variable.
>
> **Limitations.** `[e.g., single geometry; ink formulation not yet characterized; stringing
> assessed by photograph rather than quantitative rheology.]`

---

## 5. Conclusion & Future Work

***▸ What it's for:*** *One short paragraph: what you established, and the obvious next steps.
Future work is honest, not filler — it shows you know where this goes.*

**Draft:**
> We identified the cause of travel-move stringing in a PCL DIW calibration print as a
> single sticky feedrate produced by uniform speed settings, and corrected it with an
> isolated travel-speed change. `[ONE LINE ON THE OUTCOME once you have it.]` Future work
> includes adding nozzle retraction as a second stringing control, developing a
> PCL-specific (and PCL/PEO) ink profile, printing a representative scaffold geometry rather
> than a calibration cube, and — longer term — extending the workflow toward conductive
> DIW inks (Yuk et al., 2020).

---

## References

***▸ What it's for:*** *Every source you cited, in a consistent format. These three are
already in your repo's `docs/papers.md`.*

1. Zhang, J. et al. (2021). Direct ink writing of polycaprolactone / polyethylene oxide based
   3D constructs. *Progress in Natural Science: Materials International*, 31, 180–191.
2. Teixeira, M. et al. (2026). A simple method to assess the optimum 3D printing parameters,
   using agarose hydrogel. *MRS Communications*, 16, 212–218.
3. Yuk, H. et al. (2020). 3D printing of conducting polymers. *Nature Communications*, 11, 1604.

---

## Acknowledgments

***▸ What it's for:*** *Thank the funding and the people who helped but aren't authors.*

**Draft:**
> This work was supported by the National Science Foundation REU program at the IMPACT Lab,
> JSNN. The author thanks Nick Ricks for mentorship and guidance.

---

## What this mock just told you (the takeaway)

- **Sections 1, 2, 5, References, Acknowledgments:** essentially done. You could fill these tonight.
- **Sections 3 and 4 (Results, Discussion):** blocked on one thing — printing travel_fixed and photographing it.
- **The one real data gap in Methods:** what's actually in the syringe (Section 2.2). That's a question for Nick, not something you can write your way around.

So the poster's missing piece is exactly one figure: the before/after print. Everything else is reading-and-typing you already have the material for.

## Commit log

2026-06-01 initial: PrusaSlicer configs, G-code, scripts, F1500→F3600 fix
    [source.stl]
2026-06-04 docs: Day 3 — Q&A learning path + pivot to flexible electronics
